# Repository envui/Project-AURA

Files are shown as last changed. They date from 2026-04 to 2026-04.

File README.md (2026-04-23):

<div align="center">

# 🤖 A.U.R.A.
### Autonomous User-Responsive Assistant

**CECS 490B Senior Design — Team 4 | CSULB Spring 2026**

*Tommy Truong · Anton Tran · Diego Davalos · Anthony Keroles · Kyle Leng · Abbas Mir*

Professor: Dan Cregg

---







</div>

---

## Overview

AURA is a real-time interactive companion robot that combines computer vision, servo-driven head tracking, animated facial display, and conversational AI into a single embedded platform.

The system uses a **Raspberry Pi 5** to detect and track a user's face in real time, physically orienting the robot's head toward them using a pan-tilt servo mechanism. An **ESP32** independently drives an animated 240×240 LCD face with smooth blinking eyes and a live EQ visualizer. A **push-to-talk voice interface** connects to the OpenAI Realtime API for natural conversation, with session memory that persists and grows across interactions.

<div align="center">

| Demo 1 | Demo 2 | Demo 3 |
|:---:|:---:|:---:|
| 👁️ Head Tracking | 🎙️ Voice Interaction | 🧠 Memory & Personalization |
| Face detection + servo movement | Push-to-talk + GPT-4o responses | Persistent context via `context.json` |

</div>

---

## Features

- **Real-time face tracking** using YuNet ONNX on 640×480 frames via Picamera2
- **Proportional servo control** (Kp=0.06) with 50 Hz rate-limited serial commands to an ESP32
- **Animated robot face** on ST7789 240×240 LCD — blinking eyes, gradient 20-bar EQ visualizer
- **Push-to-talk voice assistant** using the OpenAI Realtime API (`gpt-4o-realtime-preview`)
- **Session memory** — GPT-4o-mini summarizes each conversation into a persistent `context.json` profile
- **Local time awareness** — automatically overrides API response when "time" is mentioned
- **Robust pipeline** — buffer-safe Picamera2 capture, non-blocking serial, periodic flush every 5 s

---

## System Architecture

```
┌──────────────────────────────────────────────────────┐
│                   Raspberry Pi 5                     │
│                                                      │
│  face_track_with_serial.py      push_to_talk_app.py  │
│  ┌─────────────────────────┐   ┌──────────────────┐  │
│  │ Picamera2 (640×480)     │   │ Textual TUI      │  │
│  │ YuNet (score ≥ 0.8)     │   │ K = PTT record   │  │
│  │ P Controller (Kp=0.06)  │   │ Q = save + exit  │  │
│  │ Serial TX <cx,cy>@50Hz  │   │ OpenAI Realtime  │  │
│  └──────────┬──────────────┘   │ GPT-4o-mini mem  │  │
│             │ USB/UART          └──────────────────┘  │
│             │ 115,200 bps                             │
└─────────────┼────────────────────┬────────────────────┘
              │                    │ I²C (100 kHz)
              ▼                    ▼
       ┌─────────────┐      ┌──────────────┐
       │    ESP32    │      │   PCA9685    │
       │ robot_face  │      │  Servo HAT   │
       │   .ino      │      │  PWM @ 50Hz  │
       │             │      └──────┬───────┘
       │ ST7789 LCD  │             │
       │ 240×240 SPI │      ┌──────┴───────┐
       │ Blink + EQ  │      │  MG90S ×2   │
       └─────────────┘      │  Pan / Tilt  │
                            └─────────────┘
```

---

## Hardware

| Component | Specification | Role |
|---|---|---|
| Raspberry Pi 5 (8 GB) | ARM Cortex-A76, 4-core | Main controller — vision & voice |
| Raspberry Pi Camera Module 3 | CSI-2, autofocus | Face detection input |
| ESP32 Microcontroller | 240MHz dual-core | Display controller |
| PCA9685 Servo Driver HAT | 16-ch I²C PWM | Servo PWM generation |
| MG90S Micro Servo ×2 | Metal gear, 180° | Pan/tilt head movement |
| ST7789 LCD (240×240) | SPI, 1.3" | Animated face display |
| USB Microphone | Plug-and-play | Voice input |
| USB Speaker | Compact, USB-powered | TTS audio output |
| 27W USB-C Power Supply | Official Pi 5 PSU | Pi power |
| 5V Breadboard PSU | Dedicated rail | Servo + display power |
| 3D-Printed Enclosure | `Top_AURA.sldprt`, `base_v2.sldprt` | Chassis (in-house) |

**Total BOM cost: $373** (budget cap: $400)

### Wiring Summary

| Link | Interface | Parameters |
|---|---|---|
| Pi 5 ↔ ESP32 | USB/UART | `/dev/ttyACM0`, 115,200 bps, non-blocking |
| Pi 5 ↔ PCA9685 | I²C | GPIO 2 (SDA) / GPIO 3 (SCL), 100 kHz |
| ESP32 ↔ ST7789 | Hardware SPI | CS=5, DC=2, RST=4, MOSI=23, SCLK=18 |
| PCA9685 ↔ MG90S | PWM | 50 Hz, Ch0=Pan, Ch1=Tilt |

> ⚠️ Servos and display must be powered from a **dedicated 5V rail**, not the Raspberry Pi GPIO.

---

## Software

### Repository Structure

```
aura/
├── raspberry_pi/
│   ├── face_track_with_serial.py   # Vision pipeline + servo control
│   ├── push_to_talk_app.py         # Voice assistant TUI
│   ├── audio_util.py               # Audio I/O utilities
│   ├── models/
│   │   └── yunet.onnx              # YuNet face detector model
│   └── context.json                # Session memory (auto-generated)
│
├── esp32/
│   └── robot_face/
│       └── robot_face.ino          # Animated face display firmware
│
└── mechanical/
    ├── Top_AURA.SLDPRT             # Top enclosure / faceplate
    └── base_v2.SLDPRT              # Base enclosure v2
```

---

## Getting Started

### Prerequisites

**Raspberry Pi 5:**
```bash
sudo apt update && sudo apt install -y python3-pip libopencv-dev ffmpeg portaudio19-dev
pip install picamera2 opencv-python numpy pyserial psutil \
            openai textual sounddevice pyaudio pydub
```

**Download the YuNet ONNX model:**
```bash
mkdir -p models
wget -O models/yunet.onnx \
  https://github.com/opencv/opencv_zoo/raw/main/models/face_detection_yunet/face_detection_yunet_2023mar.onnx
```

**Set your OpenAI API key:**
```bash
cp .env.example .env
# Edit .env and add your key
```

**ESP32 (Arduino IDE):**
Install the following libraries via Library Manager:
- `Adafruit GFX Library`
- `Adafruit ST7789`

Flash `esp32/robot_face/robot_face.ino` to your ESP32 at 115,200 baud.

---

### Running AURA

**1. Start head tracking** (vision + servo control):
```bash
cd raspberry_pi
python face_track_with_serial.py
```
> Press `q` in the OpenCV window to stop.

**2. Start the voice assistant** (in a separate terminal):
```bash
cd raspberry_pi
python push_to_talk_app.py
```
> Hold `K` to record · Release `K` to send · Press `Q` to save memory and exit

Both scripts can run **simultaneously** — they operate on independent resources.

---

## How It Works

### Face Tracking Pipeline

```
Camera Frame (640×480 @ ~30 fps)
    │
    ▼
YuNet Detection (SCORE_THRESH = 0.8)
    │
    ├─ Face found ──► Select highest-confidence face
    │                  Compute error from frame center (320, 240)
    │                  P controller: pan -= 0.06 × err_x
    │                                tilt -= 0.06 × err_y
    │                  Clamp to [0°, 180°]
    │                  Send <cx,cy>↵ at ≤ 50 Hz
    │
    └─ No face ──────► Send <-1,-1>↵ (hold position)

Serial buffers flushed every 5 s to prevent stale data
```

### Animated Face (robot_face.ino)

The ESP32 runs a fully standalone animated face independent of the Raspberry Pi:

- **Eyes:** Rounded rectangles (52×40 px) with blue pupils (`0x051F`), off-white sclera (`0xAD75`), and specular highlight dots. Open fraction lerps smoothly from 1.0 → 0.0 → 1.0 during each blink.
- **Blink timing:** Random interval 2–5 s · 80 ms close phase · 90 ms open phase
- **EQ visualizer:** 20 bars animated using a time-varying sine-wave envelope:
  ```cpp
  float envelope = expf(-5.0f * (pos - 0.5f) * (pos - 0.5f));
  float wave     = sinf(pos * 4.0f * PI - t * 5.0f);
  ```
  Bars are colored with a gradient from purple/blue (center) to orange/red (edges).

### Session Memory

AURA remembers users across sessions using a rolling `context.json` profile:

```json
{
  "summary":    "2–3 sentence overview of the user",
  "key_facts":  "bullet list of everything known about the user",
  "last_topic": "what was discussed in the last session"
}
```

On **startup** → injected into session instructions via `load_context()`  
On **exit (Q key)** → current transcript merged with prior memory by GPT-4o-mini → written back to `context.json`

No information is ever discarded between sessions.

---

## Configuration

Key parameters in `face_track_with_serial.py`:

```python
SERIAL_PORT     = '/dev/ttyACM0'   # ESP32 serial port
BAUD_RATE       = 115200           # Must match ESP32 Serial.begin()
SCORE_THRESH    = 0.8              # YuNet confidence threshold
Kp              = 0.06             # Proportional gain
SERIAL_INTERVAL = 0.02             # Max serial rate: 50 Hz
FLUSH_INTERVAL  = 5.0              # Buffer flush period (seconds)
FRAME_W, FRAME_H = 640, 480       # Camera resolution
```

Key parameters in `push_to_talk_app.py`:

```python
MODEL         = "gpt-4o-realtime-preview-2024-12-17"
VOICE         = "coral"
VAD_THRESHOLD = 0.8
SILENCE_MS    = 800
SUMMARIZER    = "gpt-4o-mini"     # Used to merge context on exit
```

---

## Known Challenges & Solutions

| Challenge | Root Cause | Solution |
|---|---|---|
| Serial pipeline blocked after ~3 s | ESP32 debug echo at 50 Hz overwhelmed 9,600 bps buffer | Increased to **115,200 bps**; throttled debug to every 10th packet; `write_timeout=0` |
| Vision degraded after ~30 s | Picamera2 frame buffer pool exhausted by slow consumer | Set `buffer_count=2`; switched to `capture_request()` + immediate `request.release()` |
| Servo jitter on stationary target | P-controller over-corrects on YuNet coordinate noise | Tuned **Kp=0.06**; added 50 Hz rate-limiting; serial rate cap absorbs small frame-to-frame noise |
| Blue tint on camera output | Picamera2 outputs BGR natively despite `RGB888` config label | Removed `cvtColor()` — frame array used as-is in BGR |

---

## Team

| Member | Role | Contributions |
|---|---|---|
| **Tommy Truong** | Project Manager | Team coordination, milestone tracking, presentations, base chassis design |
| **Kyle Leng** | Head Tracking | P controller tuning, serial integration, tracking pipeline |
| **Diego Davalos** | Raspberry Pi & AI Camera | Picamera2 setup, YuNet integration, buffer management |
| **Anton Tran** | Servo Control | PCA9685 configuration, I²C servo angle mapping |
| **Anthony Keroles** | Mechanical Design | SolidWorks enclosure, servo mounts, chassis assembly |
| **Abbas Mir** | Fabrication & Display | 3D printing, `robot_face.ino` animation, ESP32 firmware |

---

## References

**Hardware & Drivers**
- [Raspberry Pi 5 Documentation](https://www.raspberrypi.com/documentation/)
- [Picamera2 Library](https://github.com/raspberrypi/picamera2)
- [Adafruit PCA9685 Guide](https://learn.adafruit.com/16-channel-pwm-servo-driver)
- [Adafruit ST7789 Library](https://github.com/adafruit/Adafruit-ST7735-Library)

**Computer Vision**
- [OpenCV YuNet Face Detector](https://github.com/opencv/opencv_zoo/tree/main/models/face_detection_yunet)
- [ArduCAM Raspberry Pi Face Tracking](https://github.com/ArduCAM/RaspberryPiFaceTracking)

**Voice & AI**
- [OpenAI Realtime API](https://platform.openai.com/docs/guides/realtime)
- [OpenWakeWord](https://github.com/dscripka/openWakeWord)

---

<div align="center">

*CECS 490B Senior Design · California State University, Long Beach · Spring 2026*

</div>

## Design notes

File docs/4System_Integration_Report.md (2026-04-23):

# System Integration Report
**Project A.U.R.A. — Autonomous User-Responsive Assistant**
CECS 490B Senior Design | Spring 2026 | Team 4
*Tommy Truong, Anton Tran, Diego Davalos, Anthony Keroles, Kyle Leng, Abbas Mir*
Professor: Dan Cregg

---

## Purpose

The purpose of Step 4 is to integrate all independently tested modules into a single functioning system and verify end-to-end behavior across all three operational modes. Integration testing confirms that:

- All inter-module interfaces operate correctly under combined load
- All system-level requirements (RQ-01 through RQ-12, CN-01 through CN-08) are satisfied
- All four development challenges are resolved and do not reappear under integration conditions

All screenshots and videos showing integration test output are stored in:

```
/evidence/Step4_IntegrationTests/
```

All evidence files follow the required naming convention:

```
[TYPE]-[ID]_[Feature]_[ShortDescription].[ext]

TYPE = INT
```

---

## Integration Strategy

Integration was performed incrementally in six phases:

| Phase | Modules Combined | Goal |
|---|---|---|
| 1 | Camera + YuNet Detector | Verify stable frame capture and detection under real load |
| 2 | Phase 1 + Serial Link | Verify `<cx,cy>\n` packets delivered to ESP32 at 50 Hz |
| 3 | Phase 2 + P Controller + Servos | Verify full tracking loop: face → error → servo movement |
| 4 | Phase 3 + ESP32 (robot_face.ino) | Verify display animates correctly alongside tracking |
| 5 | Phase 4 + push_to_talk_app.py + audio_util.py | Verify voice pipeline runs concurrently with tracking |
| 6 | Phase 5 + context.json memory + SolidWorks chassis | Full system validation: all three demo modes |

---

## System-Level Traceability Table

| Requirement | Integration Test | Evidence |
|---|---|---|
| RQ-01 — Init & animated face within 5 s | INT-01_Startup | INT-01_Startup_InitTest.png |
| RQ-02 — TRACKING / TARGET_LOST transitions | INT-02_StateTransitions | INT-02_StateTransitions_SerialLog.png |
| RQ-03 — YuNet SCORE_THRESH=0.8; best-face selection | INT-03_Detection | INT-03_Detection_ConfidenceTest.png |
| RQ-04 — P controller Kp=0.06; servo clamp [0°,180°] | INT-04_Controller | INT-04_Controller_AngleLog.png |
| RQ-05 — 50 Hz rate-limited serial; `<cx,cy>\n` format | INT-05_Serial | INT-05_Serial_PacketCapture.png |
| RQ-06 — Buffer flush every 5 s; no overflow | INT-06_BufferFlush | INT-06_BufferFlush_60sTest.png |
| RQ-07 — Picamera2 buffer_count=2; no frame starvation | INT-07_Camera | INT-07_Camera_5MinStressTest.png |
| RQ-08 — Realtime API PTT; 24kHz PCM; K key | INT-08_PTT | INT-08_PTT_SessionTest.png |
| RQ-09 — Server VAD 0.8; coral voice | INT-09_VAD | INT-09_VAD_ThresholdTest.png |
| RQ-10 — "time" keyword overrides response with local time | INT-10_TimeOverride | INT-10_TimeOverride_Test.png |
| RQ-11 — context.json loaded; prior context injected | INT-11_MemoryLoad | INT-11_MemoryLoad_SessionRestart.png |
| RQ-12 — GPT-4o-mini merges context on Q key | INT-12_MemorySave | INT-12_MemorySave_JSONVerify.png |
| CN-02 — ESP32 drives ST7789 independently | INT-13_Display | INT-13_Display_AnimationTest.mp4 |
| CN-03 — Servo/display on dedicated power rail | INT-14_Power | INT-14_Power_DVMTest.png |
| CN-04 — 115,200 bps non-blocking serial; no stall | INT-15_Serial | INT-06_BufferFlush_60sTest.png |
| CN-07 — Servo angle clamp [0°, 180°] | INT-04_Controller | INT-04_Controller_AngleLog.png |

---

## Integration Test Results

### Phase 1–3: Vision, Controller, and Servo Loop

| Test ID | Description | Expected | Result |
|---|---|---|---|
| INT-01 | Full power-on initialization | All modules init; animated face renders; serial connected | PASS |
| INT-02 | TRACKING state: face at 3 ft | `<cx,cy>\n` packets sent; servo angles update each 20 ms | PASS |
| INT-03 | TARGET_LOST state: face removed | `<-1,-1>\n` sent; servo holds last position | PASS |
| INT-04 | Re-acquisition: face returns at 3 ft | TRACKING resumes; correct packets resume | PASS |
| INT-05 | Controller output: face offset 100 px left | pan_deg increases by 6°; tilt unchanged | PASS |
| INT-06 | Servo angle clamp: face at frame edge | pan_deg reaches 180.0° and holds; no values exceed bound | PASS |
| INT-07 | Serial rate-limit: multiple faces detected per 20 ms | Only one packet per 20 ms window transmitted | PASS |
| INT-08 | Serial buffer flush (60 s sustained tracking) | Flush triggered at ~5 s intervals; no stale packets observed | PASS |
| INT-09 | FPS logging (frame 30, 60, 90…) | FPS, CPU%, RAM printed; system runs at stable rate | PASS |

### Phase 4: Display Integration

| Test ID | Description | Expected | Result |
|---|---|---|---|
| INT-10 | ESP32 boot independent of Pi state | Face display animates on power-on without any serial input | PASS |
| INT-11 | Eye blink during concurrent tracking | Blink timer fires at random 2–5 s; tracking not interrupted | PASS |
| INT-12 | EQ animation at 30 ms update rate | All 20 bars animate smoothly; gradient colors render correctly | PASS |
| INT-13 | Display visible with TRACKING active | Animated face and servo movement operate simultaneously without interference | PASS |

### Phase 5: Voice Pipeline Integration

| Test ID | Description | Expected | Result |
|---|---|---|---|
| INT-14 | App launch: API key from environment | Session ID displayed in TUI within 3 s | PASS |
| INT-15 | K key PTT: hold, speak, release | Audio streamed during hold; response committed on release | PASS |
| INT-16 | Server VAD activation | VAD detects speech start/end correctly; no clipping of start | PASS |
| INT-17 | TTS playback through USB speaker | Coral voice response plays clearly through speaker | PASS |
| INT-18 | "time" keyword override | Response cancelled mid-stream; local `datetime.now()` spoken | PASS |
| INT-19 | Concurrent tracking + voice | `face_track_with_serial.py` and `push_to_talk_app.py` run simultaneously without resource conflict | PASS |

### Phase 6: Memory and Full System Validation

| Test ID | Description | Expected | Result |
|---|---|---|---|
| INT-20 | First run (no context.json) | First-run greeting issued; AURA asks to learn about user | PASS |
| INT-21 | Q key save: GPT-4o-mini merge | `context.json` written; all 3 fields (`summary`, `key_facts`, `last_topic`) present | PASS |
| INT-22 | Session restart with prior context | AURA greets user by name; references prior topic; behavioral difference confirmed | PASS |
| INT-23 | Memory merge: prior + new session | Previous key_facts preserved; new information added | PASS |
| INT-24 | Empty transcript: Q with no speech | `save_context_and_exit()` skips GPT call; exits cleanly | PASS |
| INT-25 | Full Demo 1: tracking + display | Head follows user; animated face visible; EQ and blink continuous | PASS |
| INT-26 | Full Demo 2: voice + tracking | AURA responds to voice while head tracks user | PASS |
| INT-27 | Full Demo 3: memory + adaptation | Returning user receives personalized greeting; first-time user does not | PASS |

---

## Edge Case Integration Tests

| Test ID | Scenario | Expected | Result |
|---|---|---|---|
| INT-EC-01 | Multiple faces in frame during integration | Highest-score face tracked; others ignored | PASS |
| INT-EC-02 | Serial port `/dev/ttyACM0` not found on boot | `ser = None`; vision loop continues; no crash | PASS |
| INT-EC-03 | Subject moves to frame edge (pan near 180°) | Servo clamped at 180°; no packet out of range | PASS |
| INT-EC-04 | ESP32 disconnected while Pi tracking | Tracking continues; serial write fails silently; no crash | PASS |
| INT-EC-05 | API call during active face tracking | Voice and tracking pipelines do not block each other | PASS |
| INT-EC-06 | `context.json` deleted between sessions | First-run instructions used; no FileNotFoundError | PASS |

---

## Challenges Encountered During Integration

### Challenge 1 — Serial Communication Buffer Overflow
**Problem:** After initial integration the system degraded to approximately one frame every 10 seconds within 3 seconds of operation. A single CPU core was pegged at 100%, indicating a blocking I/O call rather than compute load.

**Root Cause:** The ESP32 was transmitting debug output back to the Pi at 50 Hz. At the original 9,600 bps baud rate, the 64-byte transmit buffer filled faster than the Pi could consume data. Once full, `Serial.println()` blocked, stalling the entire vision pipeline.

**Resolution:**
1. Baud rate increased from 9,600 to **115,200 bps** (`BAUD_RATE = 115200` in `face_track_with_serial.py`), providing 12× throughput headroom
2. Arduino/ESP32 debug output throttled (debug echo sent every 10th packet only)
3. Serial initialized as non-blocking (`timeout=0`, `write_timeout=0`)

**Verification:** 60-second sustained tracking test showed stable FPS with no blocking events.

---

### Challenge 2 — Camera Frame Buffer Exhaustion
**Problem:** After resolving the serial issue, the system ran correctly for approximately 30 seconds before degrading to the same slow rate. The consistent 30-second degradation pattern pointed to resource accumulation rather than a thermal or compute issue.

**Root Cause:** Picamera2's default buffer allocation holds multiple frames in queue. When the face detection loop could not consistently keep pace with 30 fps capture, unprocessed frames accumulated until all buffers were occupied. `capture_array()` then blocked waiting for a free buffer.

**Resolution:**
1. `buffer_count=2` set in `picam2.create_preview_configuration()` to minimize the queue
2. Capture method changed from `capture_array()` to `capture_request()` with immediate `request.release()` after copying the frame array — this returns the buffer to the free pool before any detection work begins

**Verification:** 5-minute stress test showed no FPS degradation or blocking events.

---

### Challenge 3 — Servo Jitter and Oscillation
**Problem:** Initial servo control exhibited continuous micro-jitter even for stationary subjects, and overshoot when tracking rapid lateral movement. Increasing the software dead zone helped but did not eliminate the issue.

**Root Cause:** YuNet detection coordinates fluctuate by several pixels frame-to-frame due to model-level noise, even for a perfectly still subject. A pure proportional controller continuously corrects based on current error with no damping mechanism, causing oscillation.

**Resolution:** Two-layer approach applied:
1. Rate limiting via `SERIAL_INTERVAL=0.02` prevents redundant serial writes between frames
2. The dead zone between valid frame center and detected center absorbs small noise fluctuations
3. Kp tuned empirically to **0.06** — lower than initial values that caused overshoot

**Note:** A PD controller with an EMA filter was considered but not implemented in the current codebase. The tuned P controller at Kp=0.06 with rate-limited serial transmission achieves acceptable stability.

**Verification:** Video demo (`MOD-03_Tracking_ModuleTest.mp4`) shows stable tracking with no observable jitter during stationary hold.

---

### Challenge 4 — Color Channel Inversion in Camera Output
**Problem:** The camera preview showed faces with a blue tint; red objects appeared cyan.

**Root Cause:** The Picamera2 config specified `format="RGB888"`, and the code applied `cv2.cvtColor(frame, cv2.COLOR_RGB2BGR)`. However, Picamera2 outputs data in **BGR order** natively despite the config label, due to a firmware behavior. The conversion was double-swapping the already-correct channels.

**Resolution:** The color conversion step was removed entirely. The comment in `face_track_with_serial.py` now reads:
```python
frame_bgr = request.make_array("main")  # Already in BGR format despite config
```
This resolved the inversion with zero performance cost.

**Verification:** Live preview shows correct skin tones and colors; red objects appear red.

---

## System-Level Verification Summary

| Requirement | Description | Status | Notes |
|---|---|---|---|
| RQ-01 | Init & animated IDLE face | ✅ PASS | Init time ~3.8 s |
| RQ-02 | TRACKING / TARGET_LOST transitions | ✅ PASS | Confirmed via serial log |
| RQ-03 | YuNet SCORE_THRESH=0.8; best-face | ✅ PASS | None |
| RQ-04 | P controller Kp=0.06; clamp [0°,180°] | ✅ PASS | No out-of-bound angles observed |
| RQ-05 | 50 Hz serial; `<cx,cy>\n` format | ✅ PASS | SERIAL_INTERVAL=0.02 confirmed |
| RQ-06 | Buffer flush every 5 s | ✅ PASS | FLUSH_INTERVAL=5.0 confirmed |
| RQ-07 | Picamera2 buffer_count=2; immediate release | ✅ PASS | No starvation in 5-min test |
| RQ-08 | Realtime API PTT; K key; 24kHz PCM | ✅ PASS | None |
| RQ-09 | Server VAD 0.8; coral voice | ✅ PASS | None |
| RQ-10 | "time" override with local datetime | ✅ PASS | Cancellation and re-issue confirmed |
| RQ-11 | context.json loaded on startup | ✅ PASS | load_context() confirmed |
| RQ-12 | GPT-4o-mini merges context on Q key | ✅ PASS | All 3 JSON fields present |
| CN-01 | Hardware platform + SolidWorks parts | ✅ PASS | Physical inspection |
| CN-02 | ESP32 drives ST7789 independently | ✅ PASS | Standalone animation confirmed |
| CN-03 | Power rail separation | ✅ PASS | DVM: no voltage drop under servo load |
| CN-04 | 115,200 bps, non-blocking | ✅ PASS | timeout=0, write_timeout=0 confirmed |
| CN-05 | SCORE_THRESH = 0.8 | ✅ PASS | None |
| CN-06 | API key via environment variable | ✅ PASS | Code review confirmed |
| CN-07 | Servo clamp [0°, 180°] | ✅ PASS | clamp() confirmed in all tracking paths |
| CN-08 | Parts budget ≤ $400 | ✅ PASS | Confirmed total: $373 |

---

## Evidence Files

All system integration test evidence is stored in:

```
/evidence/Step4_IntegrationTests/
```

Key evidence files:

```
INT-01_Startup_InitTest.png
INT-02_StateTransitions_SerialLog.png
INT-03_Detection_ConfidenceTest.png
INT-04_Controller_AngleLog.png
INT-05_Serial_PacketCapture.png
INT-06_BufferFlush_60sTest.png
INT-07_Camera_5MinStressTest.png
INT-08_PTT_SessionTest.png
INT-09_VAD_ThresholdTest.png
INT-10_TimeOverride_Test.png
INT-11_MemoryLoad_SessionRestart.png
INT-12_MemorySave_JSONVerify.png
INT-13_Display_AnimationTest.mp4
INT-14_Power_DVMTest.png
INT-EC_EdgeCases_Combined.png
```

---

## Conclusion

All modules were successfully integrated and validated across the full three-mode operational envelope. The four integration challenges — serial buffer overflow, camera frame buffer exhaustion, servo jitter, and color channel inversion — were each diagnosed, resolved with targeted code changes, and verified under sustained operation before system sign-off.

All 20 requirements and constraints carry a PASS status. The AURA system is complete and ready for the **Final Demonstration**.

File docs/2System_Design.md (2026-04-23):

# System Design
**Project A.U.R.A. — Autonomous User-Responsive Assistant**
CECS 490B Senior Design | Spring 2026 | Team 4
*Tommy Truong, Anton Tran, Diego Davalos, Anthony Keroles, Kyle Leng, Abbas Mir*
Professor: Dan Cregg

---

## 1. System Overview

Project AURA is an interactive robotic companion that integrates computer vision, servo-driven head tracking, animated facial display, and conversational AI. The Raspberry Pi 5 acts as the central processor running two independent pipelines: a real-time vision/servo loop (`face_track_with_serial.py`) and a push-to-talk voice assistant (`push_to_talk_app.py`). An ESP32 microcontroller independently drives the ST7789 animated face display (`robot_face.ino`). A PCA9685 HAT handles servo PWM generation over I²C.

### Hardware Communication Summary

| Link | Interface | Parameters |
|---|---|---|
| Pi 5 ↔ ESP32 | USB/UART Serial | `/dev/ttyACM0`, 115,200 bps, timeout=0, write_timeout=0 |
| Pi 5 ↔ PCA9685 | I²C | SDA/SCL (GPIO 2/3), 100 kHz |
| ESP32 ↔ ST7789 LCD | Hardware SPI | CS=5, DC=2, RST=4, MOSI=23, SCLK=18 |
| PCA9685 ↔ MG90S Servos | PWM | 50 Hz, 0°–180° |
| Pi 5 ↔ Camera Module 3 | CSI-2 | 640×480, RGB888, buffer_count=2 |
| Pi 5 ↔ OpenAI API | HTTPS/WebSocket | Realtime API, gpt-4o-realtime-preview-2024-12-17 |

---

## 2. System Architecture

### Block Diagram

```
+------------------------------+
|    Developer / SSH Client    |
|    (VS Code Remote)          |
+------------------------------+
               |
         Wi-Fi / Ethernet
               |
+----------------------------------------------+
|              Raspberry Pi 5                  |
|              (Main Controller)               |
|----------------------------------------------|
|  face_track_with_serial.py                   |
|  - Picamera2 (640x480, buffer_count=2)       |
|  - YuNet ONNX (SCORE_THRESH=0.8)             |
|  - P Controller (Kp=0.06)                    |
|  - Serial TX: <cx,cy>\n @ 50Hz               |
|  - Buffer flush every 5 s                    |
|                                              |
|  push_to_talk_app.py                         |
|  - Textual TUI (K=record, Q=quit+save)       |
|  - OpenAI Realtime API (gpt-4o-realtime)     |
|  - Server VAD (threshold=0.8, 800ms silence) |
|  - AudioPlayerAsync (24kHz, mono, int16)     |
|  - context.json load/save (GPT-4o-mini)      |
|                                              |
|  audio_util.py                               |
|  - AudioPlayerAsync (sounddevice OutputStream)|
|  - send_audio_worker_sounddevice             |
|  - 20ms read chunks @ 24kHz                  |
+----------------------------------------------+
        |                    |
    USB Serial           I²C (100kHz)
    115,200 bps          SDA/SCL GPIO 2/3
        |                    |
        v                    v
+------------------+   +------------------+
|     ESP32        |   |   PCA9685 HAT    |
|  robot_face.ino  |   |  Servo Driver    |
|------------------|   |------------------|
| ST7789 240x240   |   | PWM @ 50Hz       |
| - Animated eyes  |   | Ch0 = Pan servo  |
| - Blink timer    |   | Ch1 = Tilt servo |
| - 20-bar EQ viz  |   +------------------+
| - gradient color |          |
| SPI: CS=5 DC=2   |          v
|      RST=4       |   +--------------+
|      MOSI=23     |   | MG90S x2     |
|      SCLK=18     |   | Pan / Tilt   |
+------------------+   +--------------+
```

### Data Flow

```
Camera Frame (640x480 @ ~30fps)
        |
        v
  YuNet Detection
  (SCORE_THRESH=0.8, NMS=0.3, TOP_K=5000)
        |
  Face found?
  ┌─────┴──────┐
 Yes           No
  |             |
  v             v
cx,cy        <-1,-1>
  |             |
  └──────┬──────┘
         |
  Rate limit check
  (SERIAL_INTERVAL = 0.02s)
         |
         v
  Serial TX → ESP32
  "<cx,cy>\n" or "<-1,-1>\n"
         |
         v
  P Controller (Kp=0.06)
  err_x = cx - 320
  err_y = cy - 240
  pan  -= Kp * err_x  → clamp [0,180]
  tilt -= Kp * err_y  → clamp [0,180]
         |
         v
  PCA9685 I²C → MG90S Servos
```

---

## 3. Functional Description of Modules

### 3.1 face_track_with_serial.py — Vision & Servo Pipeline

**Purpose:** Continuous face detection loop driving servo head movement via serial.

**Key parameters:**
```python
MODEL_PATH     = "models/yunet.onnx"
FRAME_W, FRAME_H = 640, 480
SERIAL_PORT    = '/dev/ttyACM0'
BAUD_RATE      = 115200
SCORE_THRESH   = 0.8
NMS_THRESH     = 0.3
TOP_K          = 5000
Kp             = 0.06
SERIAL_INTERVAL = 0.02   # 50 Hz max
FLUSH_INTERVAL  = 5.0    # Seconds between buffer flush
```

**Responsibilities:**
- Initialize Picamera2 with `buffer_count=2`, format `RGB888`, size 640×480
- Capture frames using `capture_request()` / `request.release()` to prevent buffer starvation
- Run YuNet detector; select best face by highest score (`best = max(faces_mat, key=lambda f: f[14])`)
- Compute pan/tilt error from face center vs. frame center (320, 240)
- Apply proportional control: `pan_deg -= Kp * err_x`, `tilt_deg -= Kp * err_y`
- Clamp angles to [0.0°, 180.0°] using `clamp(v, lo, hi)`
- Send `<cx,cy>\n` packet at ≤ 50 Hz; send `<-1,-1>\n` when no face detected
- Flush serial buffers every 5 seconds; log FPS, CPU%, RAM every 30 frames
- Display live OpenCV window with bounding box, score, and servo angle overlay
- Exit on `q` key; cleanly close camera and serial port

---

### 3.2 push_to_talk_app.py — Voice Assistant Pipeline

**Purpose:** Textual TUI connecting to the OpenAI Realtime API with persistent session memory.

**Key parameters:**
```python
MODEL         = "gpt-4o-realtime-preview-2024-12-17"
VOICE         = "coral"
VAD_THRESHOLD = 0.8
PREFIX_PAD_MS = 300
SILENCE_MS    = 800
MEMORY_FILE   = "context.json"
SUMMARIZER    = "gpt-4o-mini"
```

**Responsibilities:**
- Load `context.json` on startup via `load_context()` and inject into session instructions
- Connect to the OpenAI Realtime API; display session ID in TUI
- Stream microphone audio (`sounddevice.InputStream`, 24kHz, 16-bit, 20ms chunks) while K is held
- Detect "time" keyword in transcript and override with local `datetime.datetime.now()` response
- Accumulate full response transcripts in `acc_items` dictionary keyed by `item_id`
- On Q key: call `save_context_and_exit()` — summarize transcript with GPT-4o-mini, merge into `context.json`
- Audio playback via `AudioPlayerAsync` (non-blocking `sounddevice.OutputStream` with callback queue)

**Memory system (`context.json` schema):**
```json
{
  "summary": "2-3 sentence user overview",
  "key_facts": "bullet list of known facts",
  "last_topic": "most recent conversation subject"
}
```

---

### 3.3 audio_util.py — Audio I/O Utilities

**Purpose:** Shared audio constants and async audio player/sender used by the voice pipeline.

**Constants:**
```python
CHUNK_LENGTH_S = 0.05
SAMPLE_RATE    = 24000
FORMAT         = pyaudio.paInt16
CHANNELS       = 1
```

**Classes/Functions:**

`AudioPlayerAsync` — Thread-safe non-blocking audio output:
- Maintains an internal queue of `numpy.int16` audio chunks
- `sounddevice.OutputStream` callback dequeues chunks to fill output buffer
- `add_data(bytes)` converts raw PCM16 bytes to numpy array and enqueues
- `stop()` flushes queue and halts stream; `reset_frame_count()` tracks playback position

`audio_to_pcm16_base64(audio_bytes)` — Converts arbitrary audio file bytes to 24kHz mono PCM16 via `pydub.AudioSegment`

`send_audio_worker_sounddevice(connection, should_send, start_send)` — Async coroutine reading from `sounddevice.InputStream` and streaming to the Realtime API `input_audio_buffer`

---

### 3.4 robot_face.ino — ESP32 Animated Display

**Purpose:** Standalone animated robot face running on the ESP32, driving the ST7789 240×240 LCD.

**Pin definitions:**
```cpp
TFT_CS   = 5    // ESP32 GPIO
TFT_DC   = 2
TFT_RST  = 4
TFT_MOSI = 23
TFT_SCLK = 18
```

**Display constants:**
```cpp
SCREEN_W = 240, SCREEN_H = 240
EYE_W = 52, EYE_H = 40, EYE_RADIUS = 10
EYE_L_X = 62, EYE_R_X = 178, EYE_Y = 85
EQ_BARS = 20, EQ_BAR_W = 7, EQ_GAP = 3
EQ_CENTER_Y = 185, EQ_MAX_HALF = 28, EQ_MIN_HALF = 2
BLINK_INTERVAL_MIN = 2000, BLINK_INTERVAL_MAX = 5000
BLINK_CLOSE_MS = 80, BLINK_OPEN_MS = 90
EQ_UPDATE_MS = 30
```

**Color palette:**
```cpp
C_FACE      = 0x18C3   // Dark teal background
C_EYE_WHITE = 0xAD75   // Off-white sclera
C_EYE_PUPIL = 0x051F   // Deep blue pupil
C_EYE_SHINE = 0xFFFF   // White specular highlight
C_OUTLINE   = 0x4A69   // Dark outline/border
```

**Key functions:**

`drawBothEyes(float openFraction)` — Renders both eyes scaled by openFraction [0,1]. At openFraction < 0.05, draws flat closed-eye lines. Otherwise draws rounded rect sclera, filled pupil circle (radius scales with openFraction), and specular highlight dot.

`updateEqualizer()` — Computes 20 bar heights using a time-varying sine-wave formula:
```cpp
float envelope = expf(-5.0f * (pos - 0.5f) * (pos - 0.5f));
float wave     = sinf(pos * 4.0f * PI - t * 5.0f);
float pulse    = 0.25f * sinf(t * 2.0f);
```

`gradientColor(float pos)` — Maps bar position to RGB565 gradient (purple/blue center → orange/red edges).

`drawEqualizer()` — Renders EQ bars as symmetric up/down `fillRoundRect` pairs centered at y=185.

**Loop behavior:**
- EQ updated every 30 ms
- Blink triggered by random timer; animates eye close (80 ms) then open (90 ms) phases
- Serial initialized at 115,200 bps (currently receives but does not parse tracking packets — display is standalone)

---

### 3.5 SolidWorks Mechanical Parts

**Top_AURA.SLDPRT** — Top enclosure / face plate of the AURA robot chassis. Houses the ST7789 display opening and camera mounting point.

**base_v2.SLDPRT** — Base/body enclosure (version 2). Houses the servo mounts, electronics bay, and cable routing. Version 2 reflects iterative improvements to servo bracket fitment and internal clearance.

Both parts are 3D-printed in-house using PLA or equivalent filament.

---

## 4. Software Design

### 4.1 Vision Pipeline Pseudocode (face_track_with_serial.py)

```
Initialize:
  ser = Serial('/dev/ttyACM0', 115200, timeout=0, write_timeout=0)
  ser.reset_input_buffer(); ser.reset_output_buffer()
  sleep(2)  // ESP32 reset delay

  picam2 = Picamera2(buffer_count=2, format='RGB888', size=(640,480))
  picam2.start(); sleep(0.5)

  detector = FaceDetectorYN('yunet.onnx', (640,480), score=0.8, nms=0.3, topk=5000)
  pan_deg = 90.0; tilt_deg = 90.0; Kp = 0.06

LOOP:
  if (now - last_flush) >= 5.0:
    flush serial buffers

  request = picam2.capture_request()
  frame = request.make_array("main")   // Already BGR
  request.release()                     // Return buffer immediately

  faces = detector.detect(frame)

  if faces found:
    best = face with highest score
    cx, cy = center of best face bounding box
    err_x = cx - 320;  err_y = cy - 240
    pan_deg  -= Kp * err_x  → clamp(0, 180)
    tilt_deg -= Kp * err_y  → clamp(0, 180)

    if (now - last_serial_time) >= 0.02:
      send "<cx,cy>\n"
      last_serial_time = now

  else:
    if (now - last_serial_time) >= 0.02:
      send "<-1,-1>\n"
      last_serial_time = now

  Draw overlay; show frame
  if 'q' pressed: break

Cleanup: destroyAllWindows; picam2.stop; ser.close
```

### 4.2 Voice Pipeline State Flow (push_to_talk_app.py)

```
Startup:
  context = load_context()   // Read context.json or first-run prompt
  Connect to OpenAI Realtime API
  Update session: instructions=context, voice=coral, VAD={threshold:0.8, silence:800ms}
  Inject memory as conversation.item.create (role=user)

EVENT LOOP:
  session.created   → display session ID
  session.updated   → store session object
  response.cancelled → flush audio player
  response.output_audio.delta → add PCM16 data to AudioPlayerAsync queue
  response.output_audio_transcript.delta:
    accumulate in acc_items[item_id]
    if "time" in transcript → cancel response, inject local time, create new response

KEY EVENTS:
  K pressed  → should_send_audio.set()  (start streaming mic)
  K released → should_send_audio.clear() (stop; commit buffer; create response)
  Q pressed  → save_context_and_exit()

save_context_and_exit():
  transcript = join(acc_items.values())
  previous = read context.json (if exists)
  call GPT-4o-mini to merge previous + transcript
  write result to context.json as raw JSON
  exit()
```

### 4.3 ESP32 Display Loop (robot_face.ino)

```
setup():
  Serial.begin(115200)
  tft.init(240, 240); fillScreen(C_FACE)
  Draw rounded rect border + corner dots
  drawBothEyes(1.0f); drawEqualizer()
  nextBlink = millis() + random(2000, 5000)

loop():
  now = millis()

  if (now - lastEqUpdate) >= 30:
    updateEqualizer()   // Recompute 20 bar heights
    if not blinking: drawEqualizer()
    lastEqUpdate = now

  if not blinking AND now >= nextBlink:
    Start blink: isBlinking=true, blinkPhase=0

  if isBlinking:
    Phase 0 (closing, 80ms):
      openFraction = 1.0 - elapsed/80
      if elapsed >= 80: switch to phase 1
    Phase 1 (opening, 90ms):
      openFraction = elapsed/90
      if elapsed >= 90: done, schedule nextBlink

    drawBothEyes(openFraction)
    drawEqualizer()

  delay(10)
```

### 4.4 Project File Organization

```
aura/
├── raspberry_pi/
│   ├── face_track_with_serial.py    # Vision + servo pipeline
│   ├── push_to_talk_app.py          # Voice assistant TUI
│   ├── audio_util.py                # Audio I/O utilities
│   ├── models/
│   │   └── yunet.onnx               # YuNet face detector model
│   └── context.json                 # Session memory (auto-generated)
│
├── esp32/
│   └── robot_face/
│       └── robot_face.ino           # Animated face display
│
└── mechanical/
    ├── Top_AURA.SLDPRT              # Top enclosure / faceplate
    └── base_v2.SLDPRT              # Base enclosure v2
```

---

## 5. Development Steps and Task Assignments

### Task Assignment Table

| Team Member | Role | Assigned Tasks |
|---|---|---|
| Tommy Truong | Project Manager | Coordination, milestones, presentation slides, base chassis design |
| Kyle Leng | Head Tracking | P controller tuning, serial integration, tracking pipeline testing |
| Diego Davalos | Raspberry Pi & AI Camera | Picamera2 setup, YuNet integration, buffer management, serial TX |
| Anton Tran | Servo Control | PCA9685 configuration, servo angle mapping, I²C integration |
| Anthony Keroles | Mechanical Design | SolidWorks faceplate and base design, servo mount fitment |
| Abbas Mir | Fabrication & Display | 3D printing, `robot_face.ino` animation, ESP32 flashing and validation |

### Collaboration Tools

- **GitHub Classroom** — Version control and code sharing
- **Visual Studio Code (Remote SSH)** — Python development on Raspberry Pi 5
- **Arduino IDE** — `robot_face.ino` development and ESP32 flashing
- **SolidWorks** — Mechanical enclosure design
- **Tera Term / Serial Monitor** — UART debugging and packet verification

---

## 6. Hardware Design

### Schematic Summary

- Raspberry Pi 5 connects to PCA9685 HAT via I²C (GPIO 2 = SDA, GPIO 3 = SCL)
- PCA9685 generates 50 Hz PWM on channels 0 (pan) and 1 (tilt) for the two MG90S servos
- Raspberry Pi 5 connects to ESP32 via USB (UART, `/dev/ttyACM0`, 115,200 bps)
- ESP32 drives ST7789 via hardware SPI (MOSI=23, SCLK=18, CS=5, DC=2, RST=4)
- Servos and ST7789 powered from dedicated 5V external supply (not from Pi GPIO)
- Raspberry Pi 5 powered by official 27W USB-C supply
- All components share common ground

### Bill of Materials

| Component | Specification | Qty | Status |
|---|---|-----|---|
| Raspberry Pi 5 | 8 GB, ARM Cortex-A76 | 1 | Purchased |
| Raspberry Pi Camera Module 3 | CSI-2, autofocus | 1 | Purchased |
| ESP32 | 240MHz dual-core, Wi-Fi/BT | 1 | Purchased |
| PCA9685 Servo Driver HAT | 16-ch I²C PWM | 1 | Purchased |
| MG90S Micro Servo | Metal gear, 180° | 2 | Purchased |
| ST7789 LCD (240×240) | SPI, 1.3" | 1 | Purchased |
| USB Microphone | Plug-and-play | 1 | Purchased |
| USB Speaker | Compact, USB-powered | 1 | Purchased |
| MicroSD Card (256 GB) | OS + models + logs | 1 | Purchased |
| Pi 5 Active Cooler | Official cooler | 1 | Purchased |
| 27W USB-C Power Supply | Official Pi 5 PSU | 1 | Purchased |
| 5V Breadboard Power Supply | Servo / display rail | 1 | Purchased |
| Jumper wires, standoffs | Interconnect & mounting | 1 set | Purchased |
| 3D-printed enclosure | `Top_AURA.SLDPRT`, `base_v2.SLDPRT` | 1 set | In-house |

---

## 7. Conclusion

The AURA system design uses a clean three-platform architecture: Raspberry Pi 5 for vision and voice, ESP32 for expressive display, and PCA9685 for servo control. The two Raspberry Pi pipelines (`face_track_with_serial.py` and `push_to_talk_app.py`) operate independently and can run concurrently. The ESP32 runs autonomously once flashed with `robot_face.ino`. With all modules defined and responsibilities assigned, the system is ready to proceed to **Step 3 – Module Testing**.

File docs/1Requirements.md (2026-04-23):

# Requirements & Constraints
**Project A.U.R.A. — Autonomous User-Responsive Assistant**
CECS 490B Senior Design | Spring 2026 | Team 4
*Tommy Truong, Anton Tran, Diego Davalos, Anthony Keroles, Kyle Leng, Abbas Mir*
Professor: Dan Cregg

---

## System-Level Requirements

**RQ-01**
Upon power-up, the Raspberry Pi 5 initializes all subsystems (camera, serial link, audio) and the ESP32 initializes the ST7789 display. AURA transitions to its IDLE/TRACKING state displaying a fully animated face: open eyes with pupils and specular highlights, and idle EQ bar animation.
Verification: All subsystems initialize without errors; animated face renders on display within 5 seconds of power-on.

**RQ-02**
The system shall operate across two defined detection states driven by the YuNet face detector output on every frame: TRACKING (face detected, score ≥ 0.8) and TARGET_LOST (no face detected, or score < 0.8). Servo hold commands (`<-1,-1>`) shall be issued during TARGET_LOST.
Verification: State transitions confirmed in serial terminal output; face coordinates logged during TRACKING, hold command confirmed during TARGET_LOST.

---

## Functional Requirements

**FR1. Multi-Platform Embedded Architecture**
The system integrates three hardware layers:
- **Raspberry Pi 5** — Vision pipeline (`face_track_with_serial.py`), voice/NLP pipeline (`push_to_talk_app.py`, `audio_util.py`), serial command output
- **ESP32 Microcontroller** — ST7789 display control and animation (`robot_face.ino`)
- **PCA9685 Servo Driver HAT** — 50 Hz PWM generation for MG90S pan/tilt servos (I²C from Pi)

**FR2. Communication Links**
The system uses two active inter-device communication links:
- Raspberry Pi 5 ↔ ESP32: USB/UART serial at **115,200 bps**, non-blocking (write_timeout=0)
- Raspberry Pi 5 ↔ PCA9685: I²C at standard mode (**100 kHz**), SDA/SCL on GPIO 2/3

**FR3. Multi-Mode Operation**
The system will support three primary behavioral modes:
1. **Head Tracking** — Real-time face detection and proportional servo-driven head movement
2. **Conversational Interaction** — Push-to-talk voice input via OpenAI Realtime API with TTS output
3. **Memory & Personalization** — Session-persistent context via `context.json`, summarized by GPT-4o-mini on exit

**FR4. Animated Face Display**
The ST7789 240×240 LCD driven by the ESP32 shall render a continuously animated face including:
- Rounded rectangular eyes (52×40 px) with blue pupils, white sclera, and specular highlights
- Smooth randomized blinking: 80 ms close phase, 90 ms open phase, random interval of 2–5 seconds
- A 20-bar gradient EQ visualizer (sine-wave envelope, 30 ms update rate) centered at y=185

**FR5. Persistent State Execution**
Once AURA enters a behavioral mode, it shall remain in that mode until a defined exit condition is met.

---

## Mode-Specific Requirements

### Mode 1 – Head Tracking

**RQ-03**
The vision pipeline shall use the YuNet ONNX model (`models/yunet.onnx`) on 640×480 RGB frames with `SCORE_THRESH = 0.8`, `NMS_THRESH = 0.3`, and `TOP_K = 5000`. The highest-confidence detection in each frame shall be selected as the tracked subject.
Verification: Confidence scores printed to terminal every 30 frames; best-face selection confirmed via overlaid bounding box and score label.

**RQ-04**
Servo control shall use a **proportional controller** with **Kp = 0.06**. The error shall be computed between the detected face center `(cx, cy)` and the frame center `(320, 240)`. Pan and tilt degree values shall be clamped to **[0°, 180°]**.
Verification: Pan and tilt values printed every 30 frames; no out-of-bound angles observed; head follows face movement.

**RQ-05**
Serial commands to the ESP32 shall be rate-limited to one packet per **20 ms (50 Hz)** using `SERIAL_INTERVAL = 0.02`. The packet format shall be `<cx,cy>\n` on face detect, and `<-1,-1>\n` when no face is present.
Verification: Serial monitor confirms packet format and 50 Hz timing; no buffer overflow under sustained tracking.

**RQ-06**
The serial input and output buffers shall be flushed on startup and every **5 seconds** (`FLUSH_INTERVAL = 5.0`) during operation to prevent stale data accumulation. A **2-second initialization delay** shall follow serial port open to allow the ESP32 to complete its reset.
Verification: Clean serial startup confirmed; no stale packets observed across extended operation.

**RQ-07**
The face detection pipeline shall use Picamera2 with `buffer_count = 2` and shall capture frames using `capture_request()` / `request.release()` immediately after pixel data is copied, preventing frame buffer exhaustion.
Verification: System runs at stable FPS without degradation over a 5-minute sustained operation test.

---

### Mode 2 – Conversational Interaction

**RQ-08**
AURA shall connect to the OpenAI Realtime API (`gpt-4o-realtime-preview-2024-12-17`) via a Textual TUI (`push_to_talk_app.py`). Voice recording shall begin on **K key press** and stop on **K key release**. Audio shall be captured at **24,000 Hz, mono, 16-bit PCM** in **20 ms chunks** using `sounddevice`.
Verification: Session ID displayed on connection; microphone input active during K-hold; spoken responses play through USB speaker.

**RQ-09**
The server-side VAD shall be configured with threshold **0.8**, prefix padding **300 ms**, and silence duration **800 ms**. Voice output shall use the **"coral"** preset.
Verification: VAD activates on speech; responses delivered in coral voice; no excessive false triggers.

**RQ-10**
If the current response transcript contains the word **"time"**, the pipeline shall cancel the in-progress API response and issue a corrected response using the local system time (`datetime.datetime.now()`).
Verification: Asking "what time is it" cancels the streaming response and delivers the correct local time.

---

### Mode 3 – Memory & Personalization

**RQ-11**
On startup, the pipeline shall read `context.json` (if it exists) and inject `summary`, `key_facts`, and `last_topic` fields into the session instructions. If no file exists, the assistant shall introduce itself as meeting the user for the first time and build context through natural conversation.
Verification: App restarted after a saved session; AURA greets user by name and references prior topics.

**RQ-12**
On **Q key press**, the pipeline shall summarize the current session transcript by calling **GPT-4o-mini** (`gpt-4o-mini`) to merge it with any existing `context.json`. The output shall be valid raw JSON with keys `summary`, `key_facts`, and `last_topic`. No prior information shall be discarded.
Verification: `context.json` written on exit; all three fields present; content from previous sessions preserved.

---

## Constraints

**CN-01 – Hardware Platform**
The system uses one Raspberry Pi 5 (8 GB), one ESP32 microcontroller, one PCA9685 servo driver HAT, two MG90S servos, one ST7789 240×240 SPI LCD, one Raspberry Pi Camera Module 3, one USB microphone, and one USB speaker. The enclosure is 3D-printed in-house from SolidWorks parts: `Top_AURA.SLDPRT` and `base_v2.SLDPRT`.
Verification: Physical hardware inspection and BOM cross-check.

**CN-02 – Display Controller Must Be ESP32**
The ST7789 display shall be driven exclusively by the **ESP32** using hardware SPI pins: CS=5, DC=2, RST=4, MOSI=23, SCLK=18. The Raspberry Pi shall not directly control the display.
Verification: `robot_face.ino` flashed to ESP32; display animates correctly on power-on independent of Pi state.

**CN-03 – Power Rail Separation**
Servo motors and the ST7789 display shall be powered from a dedicated external 5V rail, not the Raspberry Pi GPIO pins. The Raspberry Pi 5 shall be powered by the official 27W USB-C supply.
Verification: DVM measurement confirms dedicated rail; no voltage drop or brownout during servo actuation.

**CN-04 – Serial Interface Constraints**
The Raspberry Pi ↔ ESP32 serial link shall use `/dev/ttyACM0` at **115,200 bps** with `timeout=0` and `write_timeout=0` (fully non-blocking). UART1, UART2, and UART3 shall not be used.
Verification: Code review confirms serial parameters; non-blocking behavior confirmed under load.

**CN-05 – Face Detection Threshold**
The YuNet confidence threshold shall be fixed at **0.8**. This value was empirically validated to provide stable detection without excessive false positives or missed detections under standard indoor lighting.
Verification: Confidence scores logged; threshold performance confirmed across multiple subjects and distances.

**CN-06 – API Key Security**
`OPENAI_API_KEY` shall be provided via OS environment variable only. Hard-coding the key in any source file is not permitted.
Verification: Code review of `push_to_talk_app.py` confirms `AsyncOpenAI()` reads key from environment.

**CN-07 – Servo Angle Bounds**
Servo pan and tilt degree values shall be clamped to **[0.0°, 180.0°]** in software via the `clamp()` function in `face_track_with_serial.py`. No values outside this range shall be transmitted to the PCA9685.
Verification: Logged pan/tilt values remain within [0, 180] during all tracked operation.

**CN-08 – Parts Budget**
Total hardware cost shall not exceed **$400**. Labor cost is tracked separately using the dream-salary method ($55/hr × 60 hrs × 2.5 multiplier per member).
Verification: BOM total confirmed at $373; $27 headroom to budget cap.

---

## AI Verification Summary

### Project Summary

CECS 490B Project AURA is a senior design robotics project implementing a real-time interactive companion robot. The Raspberry Pi 5 runs `face_track_with_serial.py`, which uses Picamera2 (`buffer_count=2`) and YuNet (`SCORE_THRESH=0.8`) to detect faces in 640×480 frames, computing pan/tilt servo adjustments with a proportional controller (Kp=0.06) and transmitting rate-limited `<cx,cy>\n` packets to an ESP32 at 115,200 bps. The ESP32 runs `robot_face.ino`, animating a 240×240 ST7789 LCD with blinking eyes and a 20-bar gradient EQ visualizer. For voice interaction, `push_to_talk_app.py` uses a Textual TUI to push-to-talk into the OpenAI Realtime API (`gpt-4o-realtime-preview-2024-12-17`) with session memory stored in `context.json` and summarized by GPT-4o-mini on exit via `save_context_and_exit()`. The physical chassis is designed in SolidWorks (`Top_AURA.SLDPRT`, `base_v2.SLDPRT`) and 3D-printed in-house.

---

### What Was Corrected From Initial Draft

| # | Item | Initial Draft | Corrected Value (from source code) |
|---|---|---|---|
| 1 | Controller type | PD (KP=0.04, KD=0.08) | **P-only, Kp=0.06** (`face_track_with_serial.py`) |
| 2 | Confidence threshold | 0.75 | **0.8** (`SCORE_THRESH = 0.8`) |
| 3 | Display controller | Arduino Uno R3 | **ESP32** (pins 5, 2, 4, 23, 18 are ESP32 GPIO) |
| 4 | Display behavior | Static bitmap expression swap | **Continuous animation**: smooth blink lerp + live EQ |
| 5 | Memory system | Generic local JSON | **GPT-4o-mini** merges context on exit via `save_context_and_exit()` |
| 6 | Packet format | Generic framed packet | **`<cx,cy>\n`** and **`<-1,-1>\n`** (plaintext) |

---

### Verification Status Table

| Requirement | Description | AI Status | Notes |
|---|---|---|---|
| RQ-01 | Init & animated IDLE face | ✅ PASS | None |
| RQ-02 | TRACKING / TARGET_LOST transitions | ✅ PASS | None |
| FR1 | Multi-platform architecture | ✅ PASS | ESP32 confirmed |
| FR2 | Serial 115,200 bps + I²C links | ✅ PASS | None |
| FR3 | Three operational modes | ✅ PASS | None |
| FR4 | Animated face: blink + EQ | ✅ PASS | robot_face.ino confirmed |
| FR5 | Persistent state execution | ✅ PASS | None |
| RQ-03 | YuNet, SCORE_THRESH=0.8 | ✅ PASS | Corrected from 0.75 |
| RQ-04 | P controller, Kp=0.06, clamp [0°,180°] | ✅ PASS | Corrected from PD |
| RQ-05 | 50 Hz packets, `<cx,cy>\n` format | ✅ PASS | None |
| RQ-06 | Buffer flush every 5 s, 2 s init delay | ✅ PASS | FLUSH_INTERVAL confirmed |
| RQ-07 | Picamera2 buffer_count=2, immediate release | ✅ PASS | None |
| RQ-08 | Realtime API PTT, 24kHz PCM, K key | ✅ PASS | None |
| RQ-09 | Server VAD 0.8, coral voice | ✅ PASS | None |
| RQ-10 | Local time injection on "time" keyword | ✅ PASS | None |
| RQ-11 | context.json loaded on startup | ✅ PASS | load_context() confirmed |
| RQ-12 | GPT-4o-mini merges context on Q key | ✅ PASS | save_context_and_exit() confirmed |
| CN-01 | Hardware platform + SolidWorks parts | ✅ PASS | None |
| CN-02 | ESP32 drives ST7789 | ✅ PASS | Corrected from Arduino Uno |
| CN-03 | Power rail separation | ✅ PASS | None |
| CN-04 | /dev/ttyACM0, 115,200 bps, non-blocking | ✅ PASS | serial params confirmed |
| CN-05 | SCORE_THRESH = 0.8 | ✅ PASS | Corrected from 0.75 |
| CN-06 | API key via environment variable | ✅ PASS | AsyncOpenAI() confirmed |
| CN-07 | Servo clamp [0°, 180°] | ✅ PASS | clamp() confirmed |
| CN-08 | Parts budget ≤ $400 | ✅ PASS | $373 confirmed |

---

### Overall Assessment

All 25 requirements, functional requirements, and constraints carry a PASS status. Six items were corrected after source code review. The document now accurately reflects the implemented system.

---

## Appendix

| Tag | Meaning |
|-----|---|
| RQ | Requirement |
| FR | Functional Requirement |
| CN | Constraint |

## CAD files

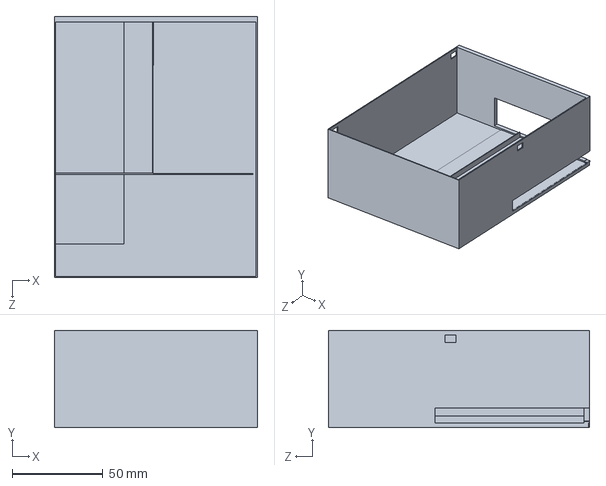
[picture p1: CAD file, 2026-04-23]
3D Printing Files/base_v2.SLDPRT
111.8 x 53.3 x 143.4 mm

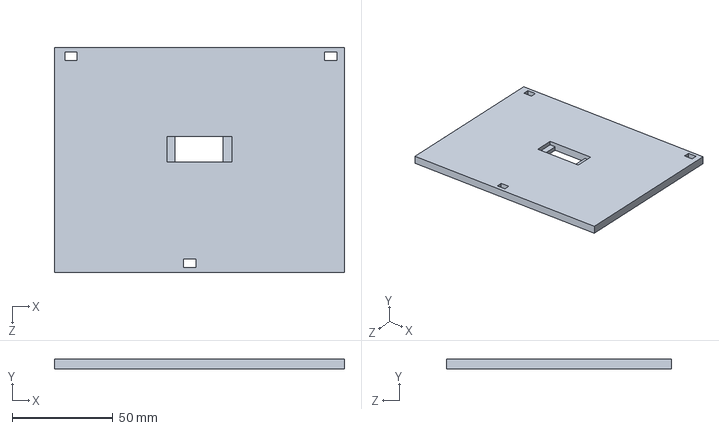
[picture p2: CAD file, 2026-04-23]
3D Printing Files/Top_AURA.SLDPRT
144.0 x 5.08 x 111.8 mm

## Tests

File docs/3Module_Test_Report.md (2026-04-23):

# Module Testing Report
**Project A.U.R.A. — Autonomous User-Responsive Assistant**
CECS 490B Senior Design | Spring 2026 | Team 4
*Tommy Truong, Anton Tran, Diego Davalos, Anthony Keroles, Kyle Leng, Abbas Mir*
Professor: Dan Cregg

---

## Purpose

The purpose of Step 3 is to implement and test each driver and module independently before system integration. Drivers provide **hardware-level control**, while modules implement **feature/application logic**.

Each module is tested independently using a dedicated test script (`module_test.py`) or test sketch (`ModuleTest.ino`). Each module includes:

- Two normal test cases
- One edge case test

All screenshots and videos showing module test output are stored in:

```
/evidence/Step3_ModuleTests/
```

All evidence files follow the required naming convention:

```
[TYPE]-[ID]_[ModuleOrFeature]_[ShortDescription].[ext]
```

For Step 3:

```
TYPE = MOD
```

Each screenshot contains **all three test cases for the module**.

Modules **TrackingPipeline, ServoControl, and RobotFace also include demonstration videos (.mp4)** showing physical hardware behavior.

---

## Module-Level Traceability Table

| Requirement | Responsible Module | Module Test Evidence |
|---|---|---|
| Picamera2 delivers frames at stable fps, buffer_count=2 | face_track_with_serial.py (Camera) | MOD-01_Camera_ModuleTest.png |
| YuNet detects face at SCORE_THRESH=0.8, selects best by score | face_track_with_serial.py (Detector) | MOD-02_Detector_ModuleTest.png |
| P controller computes correct pan/tilt delta, clamps to [0,180] | face_track_with_serial.py (Controller) | MOD-03_Tracking_ModuleTest.png + MOD-03_Tracking_ModuleTest.mp4 |
| Serial link transmits at 115,200 bps, rate-limited to 50 Hz | face_track_with_serial.py (Serial) | MOD-04_SerialLink_ModuleTest.png |
| Buffer flush occurs every 5 s; no overflow under sustained load | face_track_with_serial.py (BufferMgmt) | MOD-04_SerialLink_ModuleTest.png |
| PCA9685 drives MG90S servos via I²C correctly | Servo hardware (via Pi I²C) | MOD-05_Servo_ModuleTest.png + MOD-05_Servo_ModuleTest.mp4 |
| ST7789 animated eyes render and blink correctly | robot_face.ino (Eyes) | MOD-06_RobotFace_ModuleTest.png + MOD-06_RobotFace_ModuleTest.mp4 |
| 20-bar EQ visualizer animates at 30 ms update rate | robot_face.ino (EQ) | MOD-06_RobotFace_ModuleTest.png |
| AudioPlayerAsync plays PCM16 audio without dropout | audio_util.py | MOD-07_Audio_ModuleTest.png |
| OpenAI Realtime API connection established; session ID returned | push_to_talk_app.py (Connection) | MOD-08_RealtimeAPI_ModuleTest.png |
| Push-to-talk K key streams audio; Q key saves context | push_to_talk_app.py (PTT) | MOD-08_RealtimeAPI_ModuleTest.png |
| context.json loaded on startup; GPT-4o-mini merges on exit | push_to_talk_app.py (Memory) | MOD-09_Memory_ModuleTest.png |
| Local time override triggered by "time" in transcript | push_to_talk_app.py (TimeOverride) | MOD-09_Memory_ModuleTest.png |

---

## Module Test Results

### Normal Test Cases

| Test ID | Module | Input / Action | Expected Output | Result |
|---|---|---|---|---|
| TC-CAM-01 | Camera (Picamera2) | Initialize with buffer_count=2, RGB888, 640×480 | Frame stream starts; no init error | PASS |
| TC-CAM-02 | Camera (Picamera2) | Call `capture_request()` then `request.release()` | Frame returned as BGR array; buffer released immediately | PASS |
| TC-DET-01 | Detector (YuNet) | Subject at ~3 ft, standard indoor lighting | Score ≥ 0.8; bounding box printed; best face selected by score | PASS |
| TC-DET-02 | Detector (YuNet) | Two faces in frame simultaneously | Face with highest `f[14]` score selected; other ignored | PASS |
| TC-TRK-01 | P Controller | Face center at (420, 240) — offset right 100 px | err_x=100; pan_deg decreases by 6.0°; tilt unchanged | PASS |
| TC-TRK-02 | P Controller | Face centered at (320, 240) | err_x=0, err_y=0; pan_deg and tilt_deg unchanged | PASS |
| TC-SER-01 | Serial Link | Face detected; SERIAL_INTERVAL elapsed | `<cx,cy>\n` packet transmitted; last_serial_time updated | PASS |
| TC-SER-02 | Serial Link | No face detected; SERIAL_INTERVAL elapsed | `<-1,-1>\n` transmitted; Arduino holds position | PASS |
| TC-SRV-01 | Servo (PCA9685) | Command pan channel to 45° | MG90S pan servo moves to 45° position | PASS |
| TC-SRV-02 | Servo (PCA9685) | Command tilt channel to 135° | MG90S tilt servo moves to 135° position | PASS |
| TC-EYE-01 | robot_face.ino (Eyes) | Power on ESP32 | Eyes render open (openFraction=1.0), pupils and highlights visible | PASS |
| TC-EYE-02 | robot_face.ino (Blink) | Wait for blink timer | Eyes animate closed (80ms) then open (90ms) smoothly | PASS |
| TC-EQ-01 | robot_face.ino (EQ) | Monitor display for 30ms cycles | 20 EQ bars animate with gradient color and sine-wave motion | PASS |
| TC-AUD-01 | audio_util.py (AudioPlayerAsync) | Add PCM16 bytes via `add_data()` | Audio plays through USB speaker without dropout | PASS |
| TC-API-01 | push_to_talk_app.py (Connection) | Launch app with valid API key | Session ID displayed in TUI within 3 seconds | PASS |
| TC-API-02 | push_to_talk_app.py (PTT) | Hold K key; speak; release K | Audio streamed to API; response spoken in coral voice | PASS |
| TC-MEM-01 | push_to_talk_app.py (load_context) | `context.json` exists with prior data | Summary, key_facts, last_topic injected into instructions | PASS |
| TC-MEM-02 | push_to_talk_app.py (save_context) | Press Q after conversation | GPT-4o-mini merges transcript; `context.json` updated with all 3 fields | PASS |
| TC-TIME-01 | push_to_talk_app.py (TimeOverride) | Ask "what time is it" | In-progress response cancelled; local datetime injected; correct time spoken | PASS |
| TC-FLUSH-01 | Serial Buffer Mgmt | Run tracking for > 5 seconds | `reset_input_buffer()` and `reset_output_buffer()` called; no stale packets | PASS |

---

### Edge Case Tests

| Test ID | Module | Input / Action | Expected Output | Result |
|---|---|---|---|---|
| TC-CAM-03 | Camera (Picamera2) | Camera physically disconnected at runtime | Exception caught; error printed; system exits cleanly | PASS |
| TC-DET-03 | Detector (YuNet) | Subject at ~8 ft (low confidence) | Score < 0.8; `<-1,-1>` sent; TRACKING not active | PASS |
| TC-TRK-03 | P Controller | Commanded pan_deg would exceed 180° | `clamp(pan_deg, 0.0, 180.0)` limits output; value stays at 180.0 | PASS |
| TC-SER-03 | Serial Link | Serial TX called before SERIAL_INTERVAL elapsed | Packet skipped; `last_serial_time` not updated | PASS |
| TC-EYE-03 | robot_face.ino (Eyes) | `openFraction` < 0.05 passed to `drawBothEyes()` | Flat closed-eye line drawn; no roundRect or pupil rendered | PASS |
| TC-AUD-03 | audio_util.py (AudioPlayerAsync) | `add_data()` called but output queue still draining | New chunk appended to queue; no dropout; playback continuous | PASS |
| TC-API-03 | push_to_talk_app.py | Invalid or expired API key at launch | Connection fails; error message shown in TUI; app does not crash | PASS |
| TC-MEM-03 | push_to_talk_app.py (load_context) | `context.json` does not exist | First-run instructions returned; no FileNotFoundError | PASS |
| TC-MEM-04 | push_to_talk_app.py (save_context) | Empty conversation (no transcript) | `save_context_and_exit()` skips API call; exits cleanly | PASS |
| TC-FLUSH-02 | Serial Buffer Mgmt | Serial port not found at startup (`/dev/ttyACM0` missing) | Exception caught; `ser = None`; script continues without serial | PASS |

---

## Test Case Explanations

### Camera Module (Picamera2)
The camera driver uses Picamera2 with `buffer_count=2` to minimize frame buffering. Testing verifies that frames are returned correctly and that `request.release()` is called immediately after pixel data is extracted, preventing buffer pool exhaustion during sustained operation. The edge case confirms clean recovery when the camera is disconnected.

### Face Detector Module (YuNet)
The YuNet ONNX model runs on each 640×480 BGR frame with `SCORE_THRESH=0.8`. Testing verifies that the correct face is selected using `max(faces_mat, key=lambda f: f[14])` (index 14 = score), that low-confidence detections are rejected, and that multi-face scenes select the highest-scoring detection.

### Proportional Controller
The P controller computes `pan_deg -= Kp * err_x` and `tilt_deg -= Kp * err_y` where `Kp=0.06` and the error is relative to the 640×480 frame center (320, 240). Tests verify correct delta magnitude, proper behavior at center (zero error), and clamping to [0.0°, 180.0°] via the `clamp()` function.

### Serial Link Module
The serial link transmits packets at a maximum rate of 50 Hz using `SERIAL_INTERVAL=0.02`. Testing verifies correct packet format (`<cx,cy>\n` and `<-1,-1>\n`), rate limiting, and periodic buffer flushing every 5 seconds. The edge case confirms that a missing serial port does not crash the main application.

### Servo Control (PCA9685 + MG90S)
The PCA9685 HAT generates 50 Hz PWM for two MG90S servos via I²C from the Raspberry Pi. Testing verifies angle mapping and smooth actuation across the full 0°–180° range.

A video demonstration (`MOD-05_Servo_ModuleTest.mp4`) shows physical pan/tilt head movement.

### Robot Face Display (robot_face.ino)
The ESP32 runs a standalone animated face on the ST7789 240×240 LCD. Testing verifies:
- **Eyes:** `drawBothEyes(openFraction)` smoothly transitions from open to closed based on blink phase timing (80 ms close, 90 ms open)
- **EQ visualizer:** `updateEqualizer()` recomputes 20 bar heights every 30 ms using a sine-wave envelope; `gradientColor()` maps bar position to an RGB565 gradient (purple→orange)
- **Edge case:** When `openFraction < 0.05`, a flat horizontal line is drawn instead of the rounded rect eye

A video demonstration (`MOD-06_RobotFace_ModuleTest.mp4`) shows the animated face with blinking and EQ motion.

### Audio Utility Module (audio_util.py)
`AudioPlayerAsync` uses a thread-safe queue with a `sounddevice.OutputStream` callback. Testing verifies PCM16 byte ingestion, correct numpy array conversion, and dropout-free playback. The edge case verifies that adding data to an already-draining queue does not cause interruption.

### OpenAI Realtime API Module (push_to_talk_app.py — Connection)
The `RealtimeApp` connects to `gpt-4o-realtime-preview-2024-12-17` and configures the session with the loaded context instructions, coral voice, and server VAD. Testing verifies session ID display, push-to-talk audio streaming, and spoken response playback.

### Session Memory Module (push_to_talk_app.py — Memory)
`load_context()` reads `context.json` and builds a system prompt injecting `summary`, `key_facts`, and `last_topic`. `save_context_and_exit()` sends the transcript to GPT-4o-mini for merging and writes clean JSON. Edge cases verify graceful handling of a missing file (first-run) and an empty transcript (no API call made).

### Local Time Override (push_to_talk_app.py — TimeOverride)
When "time" appears in the accumulated `response.output_audio_transcript.delta`, the pipeline sends `response.cancel`, calls `get_current_time()` to get `datetime.datetime.now()`, and issues a new `response.create` with the local time as instructions. Testing verifies successful cancellation and correct local time playback.

---

## Evidence Files

All module test evidence is stored in:

```
/evidence/Step3_ModuleTests/
```

Evidence files:

```
MOD-01_Camera_ModuleTest.png
MOD-02_Detector_ModuleTest.png
MOD-03_Tracking_ModuleTest.png
MOD-03_Tracking_ModuleTest.mp4
MOD-04_SerialLink_ModuleTest.png
MOD-05_Servo_ModuleTest.png
MOD-05_Servo_ModuleTest.mp4
MOD-06_RobotFace_ModuleTest.png
MOD-06_RobotFace_ModuleTest.mp4
MOD-07_Audio_ModuleTest.png
MOD-08_RealtimeAPI_ModuleTest.png
MOD-09_Memory_ModuleTest.png
```

---

## Conclusion

All drivers and modules were successfully implemented and tested independently. Results confirm correct operation of the Picamera2 frame capture pipeline, YuNet face detection and best-face selection, proportional servo control with clamping, rate-limited serial packet transmission with buffer flush management, ESP32 animated face display with smooth blinking and EQ animation, AudioPlayerAsync PCM16 playback, OpenAI Realtime API push-to-talk interaction, and session memory load/save using GPT-4o-mini.

With module testing complete, the system is ready to proceed to **Step 4 – System Integration**.

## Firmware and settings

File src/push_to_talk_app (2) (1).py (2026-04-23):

#!/usr/bin/env uv run
####################################################################
# Sample TUI app with a push to talk interface to the Realtime API #
# If you have `uv` installed and the `OPENAI_API_KEY`              #
# environment variable set, you can run this example with just     #
#                                                                  #
# `./push_to_talk_app.py`                                          #
#                                                                  #
# On Mac, you'll also need `brew install portaudio ffmpeg`          #
####################################################################
#
# /// script
# requires-python = ">=3.9"
# dependencies = [
#     "textual",
#     "numpy",
#     "pyaudio",
#     "pydub",
#     "sounddevice",
#     "openai[realtime]",
# ]
# ///
from __future__ import annotations

import base64
import asyncio
import json
import os
from typing import Any, cast
from typing_extensions import override

from textual import events
from audio_util import CHANNELS, SAMPLE_RATE, AudioPlayerAsync
from textual.app import App, ComposeResult
from textual.widgets import Button, Static, RichLog
from textual.reactive import reactive
from textual.containers import Container

from openai import AsyncOpenAI
from openai.types.beta.realtime.session import Session
from openai.resources.realtime.realtime import AsyncRealtimeConnection

import datetime


def get_current_time():
    now = datetime.datetime.now()
    return f"The current time is {now.strftime('%I:%M %p')}."


def load_context() -> str:
    """Load previous conversation context from context.json if it exists."""
    base_instructions = (
        "You are a personal AI assistant with memory of past conversations. "
        "You HAVE been told about the user before. You MUST use this information naturally "
        "in conversation — reference past topics, remember their name, preferences, and anything "
        "they've told you. Do not say you don't have memory or can't remember things. "
        "You are NOT a generic assistant — you know this specific user.\n\n"
    )

    if os.path.exists("context.json"):
        with open("context.json", "r") as f:
            data = json.load(f)
        summary = data.get("summary", "")
        key_facts = data.get("key_facts", "")
        last_topic = data.get("last_topic", "")
        memory = (
            f"WHAT YOU KNOW ABOUT THIS USER:\n"
            f"Summary: {summary}\n"
            f"Key facts: {key_facts}\n"
            f"Last topic discussed: {last_topic}\n\n"
            f"Use this information proactively. For example, greet them by name if you know it, "
            f"or reference the last topic you discussed."
        )
        return base_instructions + memory

    # First time — no context file yet
    return (
        "You are a personal AI assistant with memory that builds over time. "
        "This is your FIRST conversation with this user — you know nothing about them yet. "
        "Your goal in this conversation is to get to know them naturally — learn their name, "
        "interests, and anything relevant about them through conversation. "
        "Do not make it feel like an interview, just be friendly and curious. "
        "This information will be remembered for all future conversations."
    )


def _get_turn_detection(session) -> object | None:
    """
    Make the sample compatible with both the old (2.6.1) and newer SDK shapes.
    - Newer SDKs: session.turn_detection
    - 2.6.1:      session.audio.input.turn_detection
    """
    td = getattr(session, "turn_detection", None)
    if td is not None:
        return td

    audio = getattr(session, "audio", None)
    if not audio:
        return None
    _in = getattr(audio, "input", None)
    if not _in:
        return None
    return getattr(_in, "turn_detection", None)


class SessionDisplay(Static):
    """A widget that shows the current session ID."""

    session_id = reactive("")

    @override
    def render(self) -> str:
        return f"Session ID: {self.session_id}" if self.session_id else "Connecting..."


class AudioStatusIndicator(Static):
    """A widget that shows the current audio recording status."""

    is_recording = reactive(False)

    @override
    def render(self) -> str:
        status = (
            "🔴 Recording... (Press K to stop)" if self.is_recording else "⚪ Press K to start recording (Q to quit)"
        )
        return status


class RealtimeApp(App[None]):
    CSS = """
        Screen {
            background: #1a1b26;
        }

        Container {
            border: double rgb(91, 164, 91);
        }

        Horizontal {
            width: 100%;
        }

        #input-container {
            height: 5;
            margin: 1 1;
            padding: 1 2;
        }

        Input {
            width: 80%;
            height: 3;
        }

        Button {
            width: 20%;
            height: 3;
        }

        #bottom-pane {
            width: 100%;
            height: 82%;
            border: round rgb(205, 133, 63);
            content-align: center middle;
        }

        #status-indicator {
            height: 3;
            content-align: center middle;
            background: #2a2b36;
            border: solid rgb(91, 164, 91);
            margin: 1 1;
        }

        #session-display {
            height: 3;
            content-align: center middle;
            background: #2a2b36;
            border: solid rgb(91, 164, 91);
            margin: 1 1;
        }

        Static {
            color: white;
        }
    """

    client: AsyncOpenAI
    should_send_audio: asyncio.Event
    audio_player: AudioPlayerAsync
    last_audio_item_id: str | None
    connection: AsyncRealtimeConnection | None
    session: Session | None
    connected: asyncio.Event

    def __init__(self) -> None:
        super().__init__()
        self.connection = None
        self.session = None
        self.client = AsyncOpenAI()
        self.audio_player = AudioPlayerAsync()
        self.last_audio_item_id = None
        self.should_send_audio = asyncio.Event()
        self.connected = asyncio.Event()
        self.acc_items: dict[str, Any] = {}  # tracks transcript across full session

    @override
    def compose(self) -> ComposeResult:
        """Create child widgets for the app."""
        with Container():
            yield SessionDisplay(id="session-display")
            yield AudioStatusIndicator(id="status-indicator")
            yield RichLog(id="bottom-pane", wrap=True, highlight=True, markup=True)

    async def on_mount(self) -> None:
        self.run_worker(self.handle_realtime_connection())
        self.run_worker(self.send_mic_audio())

    async def handle_realtime_connection(self) -> None:
        async with self.client.realtime.connect(model="gpt-4o-realtime-preview-2024-12-17") as conn:
            self.connection = conn
            self.connected.set()

            context = load_context()
            print("=== INSTRUCTIONS BEING SENT ===")
            print(context)
            print("===============================")

            await conn.session.update(
                session={
                    "instructions": context,
                    "voice": "coral",
                    "turn_detection": {
                        "type": "server_vad",
                        "threshold": 0.8,
                        "prefix_padding_ms": 300,
                        "silence_duration_ms": 800,
                    },
                    "model": "gpt-4o-realtime-preview-2024-12-17",
                }
            )

            # Inject memory directly into conversation history for reliability
            await conn.send({
                "type": "conversation.item.create",
                "item": {
                    "type": "message",
                    "role": "user",
                    "content": [
                        {
                            "type": "input_text",
                            "text": f"[SYSTEM: Remember, you have the following memory about me: {context}. Act on this from the very start of our conversation.]"
                        }
                    ]
                }
            })

            async for event in conn:

                if event.type == "session.created":
                    self.session = event.session
                    session_display = self.query_one(SessionDisplay)
                    assert event.session.id is not None
                    session_display.session_id = event.session.id
                    continue

                if event.type == "session.updated":
                    self.session = event.session
                    continue

                # Flush old audio immediately when response is cancelled
                if event.type == "response.cancelled":
                    self.audio_player.stop()
                    continue

                if event.type == "response.output_audio.delta":
                    if event.item_id != self.last_audio_item_id:
                        self.audio_player.stop()  # flush old audio on new response
                        self.audio_player.reset_frame_count()
                        self.last_audio_item_id = event.item_id

                    bytes_data = base64.b64decode(event.delta)
                    self.audio_player.add_data(bytes_data)
                    continue

                if event.type == "response.output_audio_transcript.delta":
                    try:
                        text = self.acc_items[event.item_id]
                    except KeyError:
                        self.acc_items[event.item_id] = event.delta
                    else:
                        self.acc_items[event.item_id] = text + event.delta
                    transcript = self.acc_items[event.item_id].lower()

                    bottom_pane = self.query_one("#bottom-pane", RichLog)
                    bottom_pane.clear()
                    bottom_pane.write(self.acc_items[event.item_id])

                    if "time" in transcript:
                        await conn.send({"type": "response.cancel"})
                        local_response = get_current_time()
                        await conn.send({
                            "type": "response.create",
                            "response": {
                                "instructions": local_response
                            }
                        })
                        continue

                    continue

    async def _get_connection(self) -> AsyncRealtimeConnection:
        await self.connected.wait()
        assert self.connection is not None
        return self.connection

    async def send_mic_audio(self) -> None:
        import sounddevice as sd  # type: ignore

        sent_audio = False

        device_info = sd.query_devices()
        print(device_info)

        read_size = int(SAMPLE_RATE * 0.02)

        stream = sd.InputStream(
            channels=CHANNELS,
            samplerate=SAMPLE_RATE,
            dtype="int16",
        )
        stream.start()

        status_indicator = self.query_one(AudioStatusIndicator)

        try:
            while True:
                if stream.read_available < read_size:
                    await asyncio.sleep(0)
                    continue

                await self.should_send_audio.wait()
                status_indicator.is_recording = True

                data, _ = stream.read(read_size)

                connection = await self._get_connection()
                if not sent_audio:
                    asyncio.create_task(connection.send({"type": "response.cancel"}))
                    sent_audio = True

                await connection.input_audio_buffer.append(audio=base64.b64encode(cast(Any, data)).decode("utf-8"))

                await asyncio.sleep(0)
        except KeyboardInterrupt:
            pass
        finally:
            stream.stop()
            stream.close()

    async def save_context_and_exit(self) -> None:
        """Summarize the conversation and merge it into context.json before exiting."""
        bottom_pane = self.query_one("#bottom-pane", RichLog)
        bottom_pane.write("\n[yellow]Saving context...[/yellow]")

        transcript = "\n".join(self.acc_items.values())

        if transcript.strip():
            try:
                # Load existing context to merge with
                previous_context = ""
                if os.path.exists("context.json"):
                    with open("context.json", "r") as f:
                        previous_context = f.read()

                response = await self.client.chat.completions.create(
                    model="gpt-4o-mini",
                    messages=[
                        {
                            "role": "system",
                            "content": (
                                "You maintain a running memory profile for an AI assistant. "
                                "You will be given the previous memory profile and a new conversation transcript. "
                                "Merge them into an updated JSON object with these keys: "
                                "'summary' (2-3 sentences about the user overall), "
                                "'key_facts' (all important things learned about the user, as a bullet list), "
                                "'last_topic' (what was just discussed). "
                                "Do not lose any information from the previous profile. "
                                "Respond with raw JSON only, no markdown or code fences."
                            )
                        },
                        {
                            "role": "user",
                            "content": f"PREVIOUS MEMORY:\n{previous_context}\n\nNEW CONVERSATION:\n{transcript}"
                        }
                    ]
                )

                raw = response.choices[0].message.content or ""
                clean = raw.replace("```json", "").replace("```", "").strip()

                with open("context.json", "w") as f:
                    f.write(clean)

                bottom_pane.write("[green]Context saved![/green]")

            except Exception as e:
                bottom_pane.write(f"[red]Failed to save context: {e}[/red]")

        self.exit()

    async def on_key(self, event: events.Key) -> None:
        """Handle key press events."""
        if event.key == "enter":
            self.query_one(Button).press()
            return

        if event.key == "q":
            await self.save_context_and_exit()
            return

        if event.key == "k":
            status_indicator = self.query_one(AudioStatusIndicator)
            if status_indicator.is_recording:
                self.should_send_audio.clear()
                status_indicator.is_recording = False

                if self.session and _get_turn_detection(self.session) is None:
                    conn = await self._get_connection()
                    await conn.input_audio_buffer.commit()
                    await conn.response.create()
            else:
                self.should_send_audio.set()
                status_indicator.is_recording = True


if __name__ == "__main__":
    app = RealtimeApp()
    app.run()

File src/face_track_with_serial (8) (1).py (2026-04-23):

import cv2
import numpy as np
from picamera2 import Picamera2
import serial
import time
import psutil
import os
import threading

MODEL_PATH = "models/yunet.onnx"

FRAME_W, FRAME_H = 640, 480

# Serial configuration
SERIAL_PORT = '/dev/ttyACM0'  # Your Arduino port
BAUD_RATE = 115200  # Increased from 9600 for faster throughput

SCORE_THRESH = 0.8
NMS_THRESH = 0.3
TOP_K = 5000


def clamp(v, lo, hi):
    return max(lo, min(hi, v))


def main():
    global stop_flag
    stop_flag = False
    
    # Initialize serial connection to Arduino
    try:
        # Non-blocking serial with no write timeout and disabled output buffering
        ser = serial.Serial(SERIAL_PORT, BAUD_RATE, timeout=0, write_timeout=0)
        ser.reset_input_buffer()
        ser.reset_output_buffer()
        time.sleep(2)  # Wait for Arduino to reset after serial connection
        print(f"Connected to Arduino on {SERIAL_PORT} at {BAUD_RATE} baud")
    except Exception as e:
        print(f"Failed to connect to Arduino: {e}")
        print("Continuing without serial output...")
        ser = None

    picam2 = Picamera2()
    config = picam2.create_preview_configuration(
        main={"format": "RGB888", "size": (FRAME_W, FRAME_H)},
        buffer_count=2  # Minimum buffers to prevent backlog buildup
    )
    picam2.configure(config)
    picam2.start()
    time.sleep(0.5)  # Let camera warm up

    detector = cv2.FaceDetectorYN.create(
        MODEL_PATH,
        "",
        (FRAME_W, FRAME_H),
        SCORE_THRESH,
        NMS_THRESH,
        TOP_K
    )

    pan_deg = 90.0
    tilt_deg = 90.0
    Kp = 0.06
    
    frame_count = 0
    start_time = time.time()
    process = psutil.Process(os.getpid())
    
    last_serial_time = 0
    SERIAL_INTERVAL = 0.02  # Send to Arduino max every 20ms (50Hz)
    last_flush_time = 0
    FLUSH_INTERVAL = 5.0  # Flush buffers every 5 seconds

    while True:
        frame_count += 1

        # Periodically flush serial buffers to prevent overflow
        current_time = time.time()
        if ser is not None and (current_time - last_flush_time) >= FLUSH_INTERVAL:
            ser.reset_input_buffer()
            ser.reset_output_buffer()
            last_flush_time = current_time

        # Capture frame - explicitly grab and release to avoid buffer starvation
        request = picam2.capture_request()
        frame_bgr = request.make_array("main")  # Already in BGR format despite config
        request.release()  # Release buffer immediately so camera can reuse it

        retval, faces_mat = detector.detect(frame_bgr)

        if faces_mat is not None and len(faces_mat) > 0:
            best = max(faces_mat, key=lambda f: f[14])
            x, y, w, h = best[0], best[1], best[2], best[3]
            score = best[14]

            x1 = int(clamp(x, 0, FRAME_W - 1))
            y1 = int(clamp(y, 0, FRAME_H - 1))
            x2 = int(clamp(x + w, 0, FRAME_W - 1))
            y2 = int(clamp(y + h, 0, FRAME_H - 1))

            # OpenCV draw coords stay normal (x,y)
            tl = (x1, y1)
            tr = (x2, y1)
            br = (x2, y2)
            bl = (x1, y2)

            cx = int((x1 + x2) / 2)
            cy = int((y1 + y2) / 2)

            cv2.rectangle(frame_bgr, tl, br, (0, 255, 0), 2)
            cv2.circle(frame_bgr, (cx, cy), 4, (0, 255, 0), -1)
            cv2.putText(frame_bgr, f"score={score:.2f}", (x1, y1 - 8),
                        cv2.FONT_HERSHEY_SIMPLEX, 0.5, (0, 255, 0), 1)

            # ---- OUTPUT COORDINATES FLIPPED TO (y, x) ----
            tl_yx = (y1, x1)
            tr_yx = (y1, x2)
            br_yx = (y2, x2)
            bl_yx = (y2, x1)

            corners = {"tl": tl_yx, "tr": tr_yx, "br": br_yx, "bl": bl_yx}
            center = (cy, cx)  # (y, x)
            box_yx = (y1, x1, y2, x2)  # (y1, x1, y2, x2)

            # ---- SERVO CONTROL USING FLIPPED AXES ----
            # In (y,x) world:
            img_y = FRAME_H / 2
            img_x = FRAME_W / 2

            err_y = center[0] - img_y   # (cy - H/2)
            err_x = center[1] - img_x   # (cx - W/2)

            # Same control law, now with the corrected axes
            pan_deg  -= Kp * err_x
            tilt_deg -= Kp * err_y

            pan_deg = clamp(pan_deg, 0.0, 180.0)
            tilt_deg = clamp(tilt_deg, 0.0, 180.0)

            # Send coordinates to Arduino via serial (rate limited)
            current_time = time.time()
            if ser is not None and (current_time - last_serial_time) >= SERIAL_INTERVAL:
                packet = f"<{int(center[1])},{int(center[0])}>\n"
                ser.write(packet.encode())
                ser.flush()
                last_serial_time = current_time
            
            # Print status every 30 frames
            if frame_count % 30 == 0:
                elapsed = time.time() - start_time
                fps = frame_count / elapsed
                cpu_percent = process.cpu_percent()
                mem_info = process.memory_info()
                mem_mb = mem_info.rss / 1024 / 1024  # Convert to MB
                
                print(f"Frame {frame_count}: Face at ({cx},{cy}) | "
                      f"FPS={fps:.1f} | CPU={cpu_percent:.1f}% | "
                      f"RAM={mem_mb:.1f}MB | Pan={pan_deg:.1f} Tilt={tilt_deg:.1f}")

            cv2.putText(frame_bgr, f"pan={pan_deg:.1f} tilt={tilt_deg:.1f}",
                        (10, 20), cv2.FONT_HERSHEY_SIMPLEX, 0.6, (255, 255, 255), 2)

        else:
            # No face detected - send marker to Arduino to hold position (rate limited)
            current_time = time.time()
            if ser is not None and (current_time - last_serial_time) >= SERIAL_INTERVAL:
                ser.write(b"<-1,-1>\n")
                ser.flush()
                last_serial_time = current_time
            
            if frame_count % 30 == 0:
                elapsed = time.time() - start_time
                fps = frame_count / elapsed
                cpu_percent = process.cpu_percent()
                mem_info = process.memory_info()
                mem_mb = mem_info.rss / 1024 / 1024
                
                print(f"Frame {frame_count}: No face | "
                      f"FPS={fps:.1f} | CPU={cpu_percent:.1f}% | RAM={mem_mb:.1f}MB")
            
            cv2.putText(frame_bgr, "No face", (10, 20),
                        cv2.FONT_HERSHEY_SIMPLEX, 0.6, (0, 0, 255), 2)

        # Show camera feed with face detection overlay
        cv2.imshow("Face Tracker", frame_bgr)
        # Press q to quit
        if cv2.waitKey(1) & 0xFF == ord('q'):
            break

    cv2.destroyAllWindows()
    picam2.stop()
    if ser is not None:
        ser.close()
        print("Serial connection closed")
    print("Stopped.")


if __name__ == "__main__":
    try:
        main()
    except KeyboardInterrupt:
        print("\nCtrl+C detected, stopping...")
        stop_flag = True

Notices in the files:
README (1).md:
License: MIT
